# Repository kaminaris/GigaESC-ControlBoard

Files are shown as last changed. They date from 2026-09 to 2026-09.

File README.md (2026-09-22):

# GigaControl

Compact six-layer control card for modular GigaESC motor controllers. The MCU, CAN transceiver, IMU and signal conditioning live here; the MOSFET power stage and power supply are separate boards.

## Board views

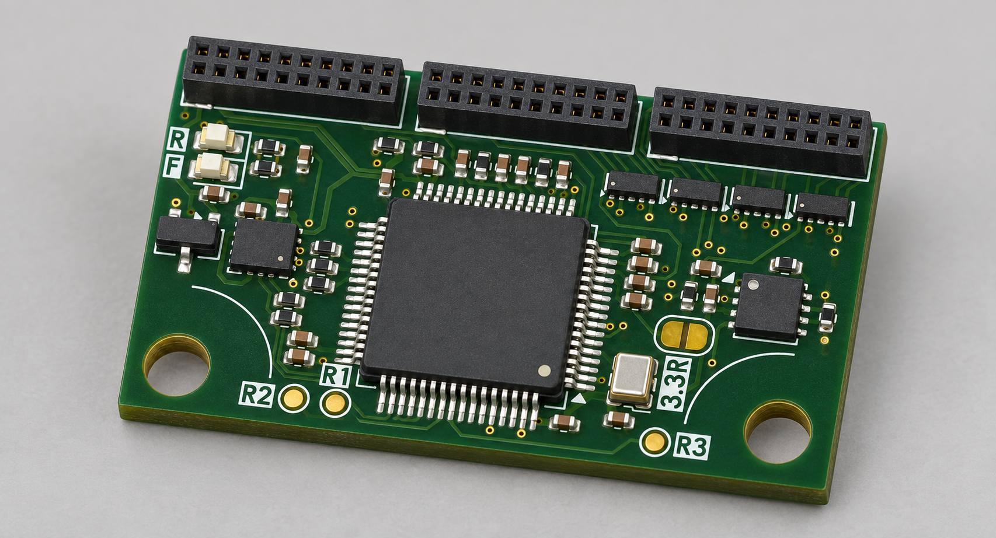
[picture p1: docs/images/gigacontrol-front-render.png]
GigaControl component side


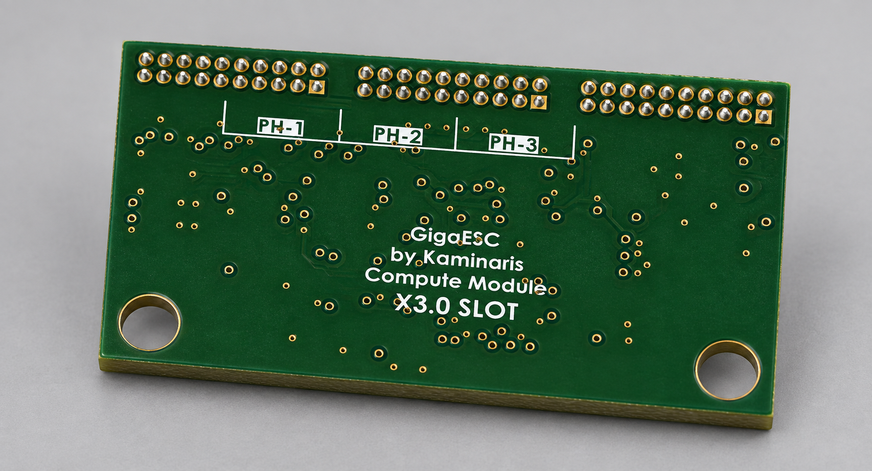
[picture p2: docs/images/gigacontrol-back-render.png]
GigaControl back side


## Hardware

- STM32F405RGT6 with an 8 MHz oscillator.
- SIT3051 CAN transceiver with onboard 120 Ω termination.
- LSM6DS3TR-C IMU on I²C.
- REF3033 analog supply/reference, also exported to the power board.
- Three 1 mm pitch 2×10 female sockets for power, PWM, feedback and external interfaces.
- USB data, SWD, Hall inputs, motor temperature, SERVO, UART and shared SPI/ADC signals pass through the power board.

Open `GigaControl.kicad_pro` in KiCad 10. Local symbols and footprints are included. Keep `HDR-TH_20P-P1.00-V-F-R2-C10-S1.00.step` beside the project for the connector models. Some other models still use `KICAD9_3DMODEL_DIR`; configure that variable if they are missing in KiCad 10.

See [connector pinout](CONNECTOR_PINOUT.md) for the current interface and [firmware adaptation guide](bldc-config/VESC-CONFIG-GUIDE.md) for the supplied VESC configuration template.

## Design notes

- 1 µF VCAP capacitors, the shared SPI/ADC filtering and the REF3033 arrangement are intentional choices reported tested by the designer. This does not imply validation of every optional interface mode.
- Bridge JP1 only when U3 (REF3033) is not fitted; it supplies VDDA from the main 3.3 V rail.
- Phase numbering is local to each board. The current GigaDFN56 pairing exchanges phase groups 1 and 3 consistently across PWM and feedback; phase 2 is unchanged.
- Adapt the firmware configuration to the actual power board and application before use.

## Repository housekeeping

Keep the KiCad project, active schematic sheets (`MCU`, `Filters`, `CAN`, `IMU`), local libraries, library tables, connector STEP model and firmware configuration sources.

Cleanup candidates, not deleted:

- Regenerable/local files: `fp-info-cache`, `GigaControl.dsn`, `GigaControl.step`, `.idea/`, `*.kicad_prl`, and `_autosave-*`.
- Old recovery files: `X3.0CH-Library.bak` and `GigaControl-backups/`, once their contents are no longer needed. Leave active lock files alone while KiCad is open.
- Unreferenced schematic files: `Connectors.kicad_sch`, `ESP32.kicad_sch`, and the empty `Power.kicad_sch`. Archive or remove after confirming they are not wanted as design references.
- Legacy footprints: `X3.0CH-Master`, `X3.0CH`, and `SolderJumper-3-0.5-Small` are not used by the current board; retain if other projects share this library.
- `production/` contains generated outputs; preserve any release/manufacturing records that still matter.

Review on 2026-09-22: saved-board DRC reports no violations, unconnected items or schematic mismatches. ERC has one warning for PB2 tied to GND. These checks do not replace hardware validation.

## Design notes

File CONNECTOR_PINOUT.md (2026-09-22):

# GigaControl connector pinout

Generated from the saved schematic on 2026-09-22. Pin numbers refer to the control-card sockets, not a viewing direction. Match numbered physical contacts on the mating power board.

J1–J3: 1 mm pitch 2×10 female sockets, local footprint `Hanxia_HX_PM1.0-2x10P_ZC`.

| Connector | Odd pin | Signal | Even pin | Signal |
|---|---:|---|---:|---|
| J1 | 1 | `+5V` | 2 | `GND` |
| J1 | 3 | `+3.3V` | 4 | `+3.3REF` |
| J1 | 5 | `POWER-STAGE-DISABLE` | 6 | `POWER-STAGE-LOCKOUT` |
| J1 | 7 | `MOSTEMP3` | 8 | `IN-V` |
| J1 | 9 | `H3` | 10 | `GND` |
| J1 | 11 | `L3` | 12 | `GND` |
| J1 | 13 | `CURR3-FILTERED` | 14 | `GND` |
| J1 | 15 | `VSENSE3` | 16 | `GND` |
| J1 | 17 | `MOSTEMP2` | 18 | `GND` |
| J1 | 19 | `H2` | 20 | `GND` |
| J2 | 1 | `L2` | 2 | `GND` |
| J2 | 3 | `CURR2-FILTERED` | 4 | `GND` |
| J2 | 5 | `VSENSE2` | 6 | `GND` |
| J2 | 7 | `MOSTEMP1` | 8 | `GND` |
| J2 | 9 | `H1` | 10 | `GND` |
| J2 | 11 | `L1` | 12 | `GND` |
| J2 | 13 | `CURR1-FILTERED` | 14 | `GND` |
| J2 | 15 | `VSENSE1` | 16 | `GND` |
| J2 | 17 | `SPI1-NSS` | 18 | `SPI1-MOSI` |
| J2 | 19 | `SPI1-SCK-ADC` | 20 | `SPI1-MISO-ADC2` |
| J3 | 1 | `USBD+` | 2 | `USBD-` |
| J3 | 3 | `SWDIO` | 4 | `GND` |
| J3 | 5 | `SWCLK` | 6 | `I2C2-SDA/USART3-RX` |
| J3 | 7 | `GND` | 8 | `I2C2-SCL/USART3-TX` |
| J3 | 9 | `HALL1-IN` | 10 | `GND` |
| J3 | 11 | `HALL2-IN` | 12 | `SERVO` |
| J3 | 13 | `HALL3-IN` | 14 | `IN-CANL` |
| J3 | 15 | `TEMPMOTOR-IN` | 16 | `IN-CANH` |
| J3 | 17 | `NRST` | 18 | `GND` |
| J3 | 19 | `ESP-TX` | 20 | `ESP-RX` |

J1/J2/J3 mate with GigaDFN56 J31/J32/J33 respectively. Control phase 1 maps to power-board phase 3, phase 2 to phase 2, and phase 3 to phase 1; each mapping includes H, L, current, phase voltage and MOSFET temperature. Other signals match directly.

J1 pin 4 exports the analog reference; J1 pin 8 receives divided bus voltage. No raw battery voltage crosses this interface. USB carries data and ground only; the external connector is on the power board.

The connectors are unkeyed. Verify orientation, insertion depth and mechanical support against the assembled boards.

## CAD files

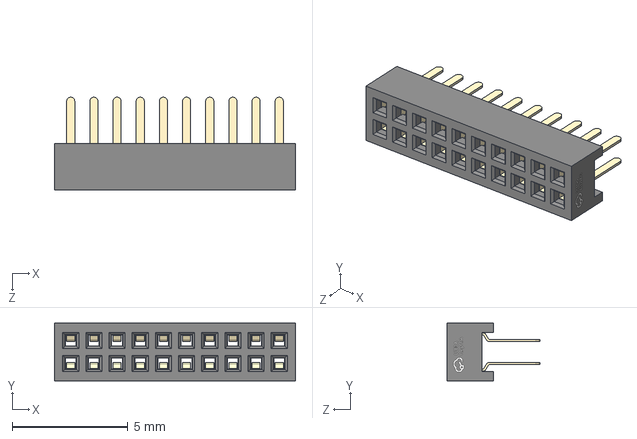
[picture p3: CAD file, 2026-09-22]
HDR-TH_20P-P1.00-V-F-R2-C10-S1.00.step
10.4 x 2.50 x 4.00 mm

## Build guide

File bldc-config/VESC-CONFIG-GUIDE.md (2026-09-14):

# BLDC / VESC config adaptation guide

The files in this folder are a **starting hardware configuration** for this compute module:

- `hw_giga_devkit_xkb_v3.h`
- `hw_giga_devkit_xkb_v3.c`

They are meant to be reused when building a custom VESC power board around this module, but several values must be updated for the final hardware.

## What this config represents

- Compute-module side (STM32, interface signals, logic-level control, basic mappings)
- A reference power-stage assumption used during development

If your gate driver, shunts, divider ratios, thermistors, or protection strategy differ, this config must be edited before production use.

## Integration into VESC firmware

1. Copy these two files into your VESC firmware hardware config area.
2. Build with the matching target:
   - `make -j24 giga_devkit_xkb_v3`
3. Flash firmware and validate on low-voltage/current-limited supply first.

## Parameters that usually require changes

| Area | Where | Typical reason to change |
|---|---|---|
| Input voltage scaling | `VIN_R1`, `VIN_R2` in `.h` | Your bus-voltage divider uses different resistor values |
| Current measurement model | `CURRENT_SHUNT_RES`, `CURRENT_AMP_GAIN`, `BOOST_*` in `.h` | Different shunt value, amplifier gain, or sensor topology |
| Current calibration | `CURRENT_CAL1/2/3` in `.h` | Remove phase gain mismatch after hardware bring-up |
| ADC channel mapping | `hw_setup_adc_channels()` in `.c`, ADC index macros in `.h` | Your analog nets are routed to different MCU ADC pins |
| Temperature model | `NTC_TEMP_*`, beta assumptions in `.h` | Different NTC beta/value or placement |
| Driver polarity / fault behavior | `ENABLE_GATE`, `DISABLE_GATE`, `IS_DRV_FAULT` in `.h` | Different gate driver enable polarity or fault pin polarity |
| Dead time | `HW_DEAD_TIME_NSEC` in `.h` | Different MOSFET + driver switching characteristics |
| Electrical limits | `HW_LIM_*`, `MCCONF_L_*`, `MCCONF_FOC_*` in `.h` | Match voltage, current, thermal, ERPM, and duty limits to your power stage |

## Minimum checklist before first full-power test

1. Confirm pinout/mappings against your power-board schematic.
2. Recalculate and set voltage divider and current-sense parameters.
3. Verify gate enable and fault polarity with scope/logic checks.
4. Set conservative voltage/current/temperature limits.
5. Calibrate current channels (`CURRENT_CAL1/2/3`), then re-test.
6. Increase limits gradually only after thermal and fault behavior is verified.

## Recommended workflow for new power boards

1. Keep this compute-module mapping as baseline.
2. Fork the config under a new board name (do not overwrite blindly).
3. Update electrical model values first (voltage/current/temp).
4. Update protection and limits.
5. Perform staged bring-up: low-voltage -> nominal voltage -> load testing.

This approach keeps the compute module reusable while allowing safe tuning for each new power board design.

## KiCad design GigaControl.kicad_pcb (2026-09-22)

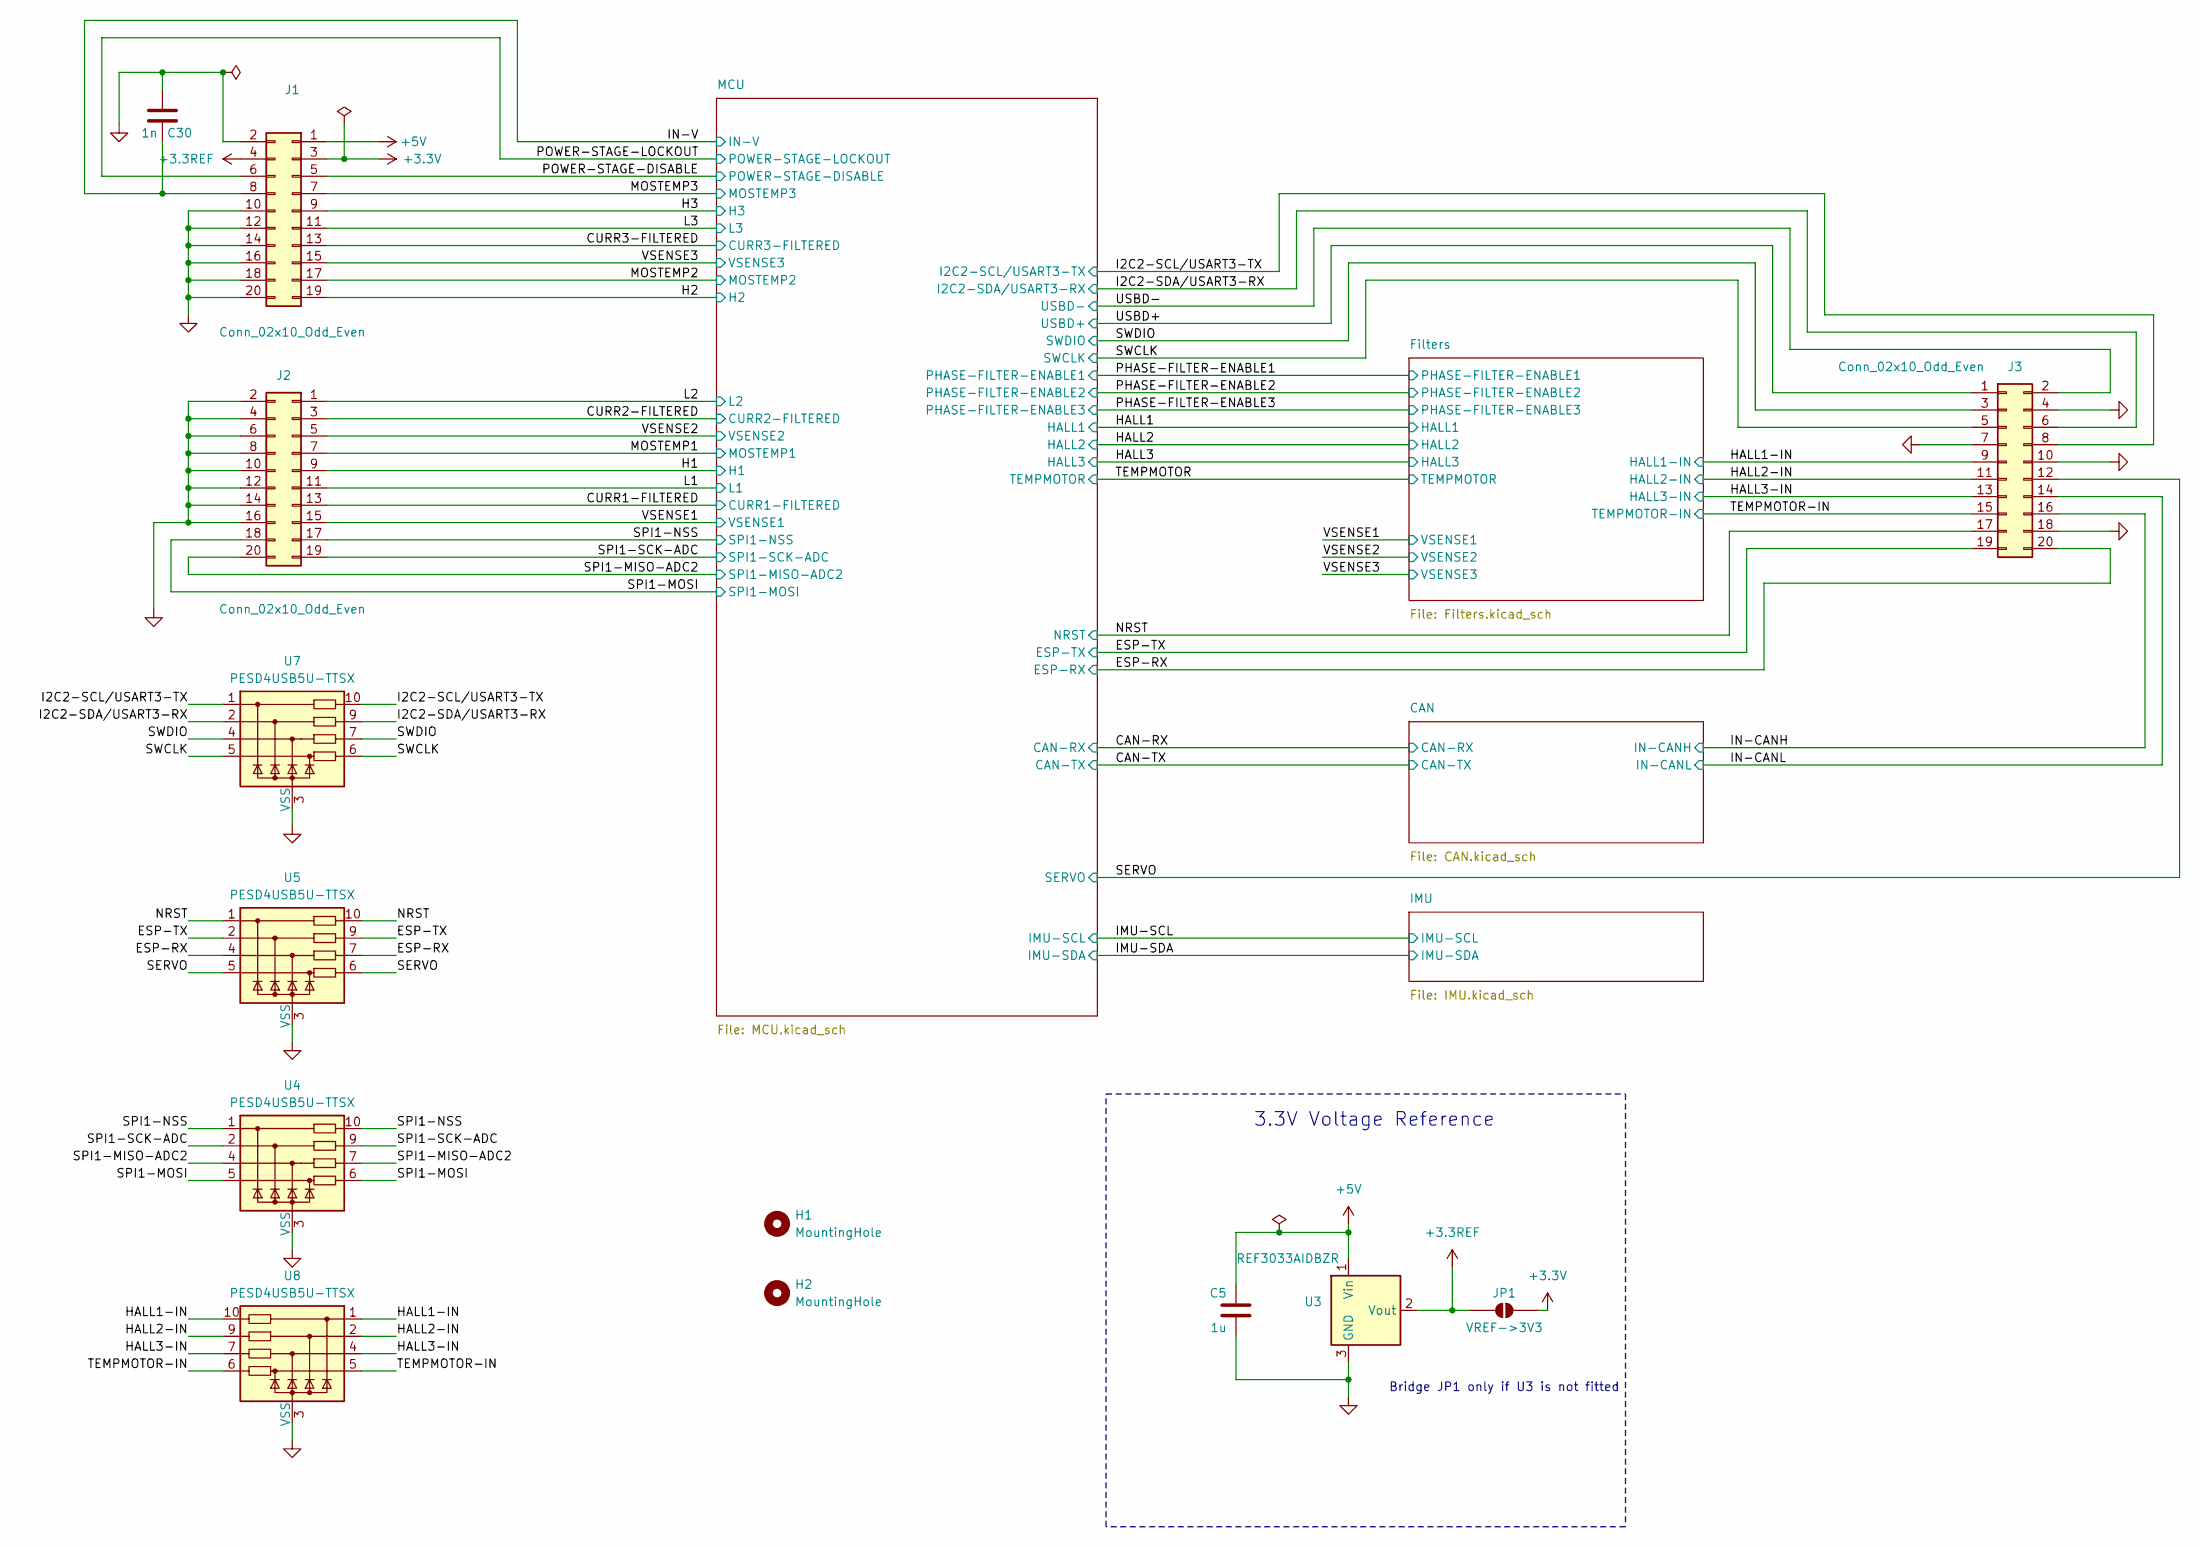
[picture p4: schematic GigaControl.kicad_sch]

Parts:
C5: 1u; C_0402_1005Metric; MPN C52923
C30: 1n; C_0402_1005Metric; MPN C1523
H1, H2: MountingHole; MountingHole_3.2mm_M3_DIN965
J1, J2, J3: Conn_02x10_Odd_Even; Hanxia_HX_PM1.0-2x10P_ZC; MPN HX PM1.0-2x10P ZC; LCSC C22465702
JP1: VREF->3V3; SolderJumper-2_P1.3mm_Open_RoundedPad1.0x1.5mm
U3: REF3033AIDBZR; SOT-23; MPN C36658; JLCRotOffset 0
U4, U5, U7, U8: PESD4USB5U-TTSX; Diodes_UDFN-10_1x2.5mm_P0.5mm

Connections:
+3.3REF: J1.4, JP1.1 (A), U3.2 (Vout); also elsewhere on the board
+3.3V: J1.3, JP1.2 (B); also elsewhere on the board
+5V: C5.1, J1.1, U3.1 (Vin)
/CURR1-FILTERED: J2.13; also elsewhere on the board
/CURR2-FILTERED: J2.3; also elsewhere on the board
/CURR3-FILTERED: J1.13; also elsewhere on the board
/ESP-RX: J3.20, U5.4, U5.7; also elsewhere on the board
/ESP-TX: J3.19, U5.2, U5.9; also elsewhere on the board
/H1: J2.9; also elsewhere on the board
/H2: J1.19; also elsewhere on the board
/H3: J1.9; also elsewhere on the board
/HALL1-IN: J3.9, U8.1, U8.10; also elsewhere on the board
/HALL2-IN: J3.11, U8.2, U8.9; also elsewhere on the board
/HALL3-IN: J3.13, U8.4, U8.7; also elsewhere on the board
/I2C2-SCL/USART3-TX: J3.8, U7.1, U7.10; also elsewhere on the board
/I2C2-SDA/USART3-RX: J3.6, U7.2, U7.9; also elsewhere on the board
/IN-CANH: J3.16; also elsewhere on the board
/IN-CANL: J3.14; also elsewhere on the board
/IN-V: C30.1, J1.8; also elsewhere on the board
/L1: J2.11; also elsewhere on the board
/L2: J2.1; also elsewhere on the board
/L3: J1.11; also elsewhere on the board
/MOSTEMP1: J2.7; also elsewhere on the board
/MOSTEMP2: J1.17; also elsewhere on the board
/MOSTEMP3: J1.7; also elsewhere on the board
/NRST: J3.17, U5.1, U5.10; also elsewhere on the board
/POWER-STAGE-DISABLE: J1.5; also elsewhere on the board
/POWER-STAGE-LOCKOUT: J1.6; also elsewhere on the board
/SERVO: J3.12, U5.5, U5.6; also elsewhere on the board
/SPI1-MISO-ADC2: J2.20, U4.4, U4.7; also elsewhere on the board
/SPI1-MOSI: J2.18, U4.5, U4.6; also elsewhere on the board
/SPI1-NSS: J2.17, U4.1, U4.10; also elsewhere on the board
/SPI1-SCK-ADC: J2.19, U4.2, U4.9; also elsewhere on the board
/SWCLK: J3.5, U7.5, U7.6; also elsewhere on the board
/SWDIO: J3.3, U7.4, U7.7; also elsewhere on the board
/TEMPMOTOR-IN: J3.15, U8.5, U8.6; also elsewhere on the board
/USBD+: J3.1; also elsewhere on the board
/USBD-: J3.2; also elsewhere on the board
/VSENSE1: J2.15; also elsewhere on the board
/VSENSE2: J2.5; also elsewhere on the board
/VSENSE3: J1.15; also elsewhere on the board
GND: C5.2, C30.2, J1.2, J1.10, J1.12, J1.14, J1.16, J1.18, J1.20, J2.2, J2.4, J2.6, J2.8, J2.10, J2.12, J2.14, J2.16, J3.4, J3.7, J3.10, J3.18, U3.3 (GND), U4.3 (VSS), U4.8 (VSS), U5.3 (VSS), U5.8 (VSS), U7.3 (VSS), U7.8 (VSS), U8.3 (VSS), U8.8 (VSS); also elsewhere on the board

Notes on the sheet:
3.3V Voltage Reference
Bridge JP1 only if U3 is not fitted

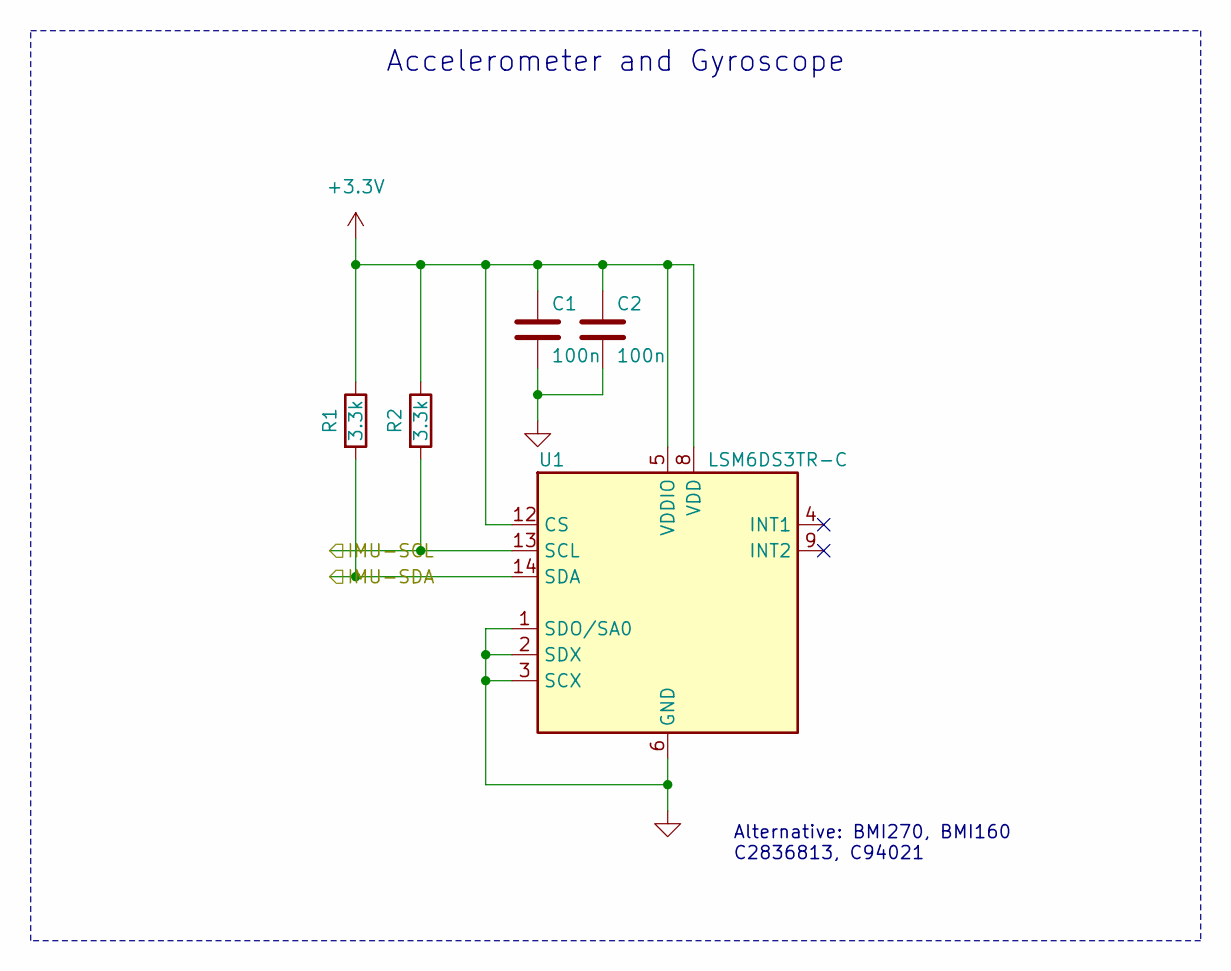
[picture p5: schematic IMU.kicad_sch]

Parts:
C1, C2: 100n; C_0402_1005Metric; MPN C1525
R1, R2: 3.3k; R_0402_1005Metric; MPN C25890
U1: LSM6DS3TR-C; LGA-14_3x2.5mm_P0.5mm; MPN C967633; JLCRotOffset -90

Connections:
+3.3V: C1.1, C2.1, R1.1, R2.1, U1.5 (VDDIO), U1.8 (VDD), U1.12 (CS); also elsewhere on the board
/IMU-SCL: R2.2, U1.13 (SCL); also elsewhere on the board
/IMU-SDA: R1.2, U1.14 (SDA); also elsewhere on the board
GND: C1.2, C2.2, U1.1 (SDO/SA0), U1.2 (SDX), U1.3 (SCX), U1.6 (GND), U1.7 (GND); also elsewhere on the board

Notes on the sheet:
Alternative: BMI270, BMI160 C2836813, C94021
Accelerometer and Gyroscope

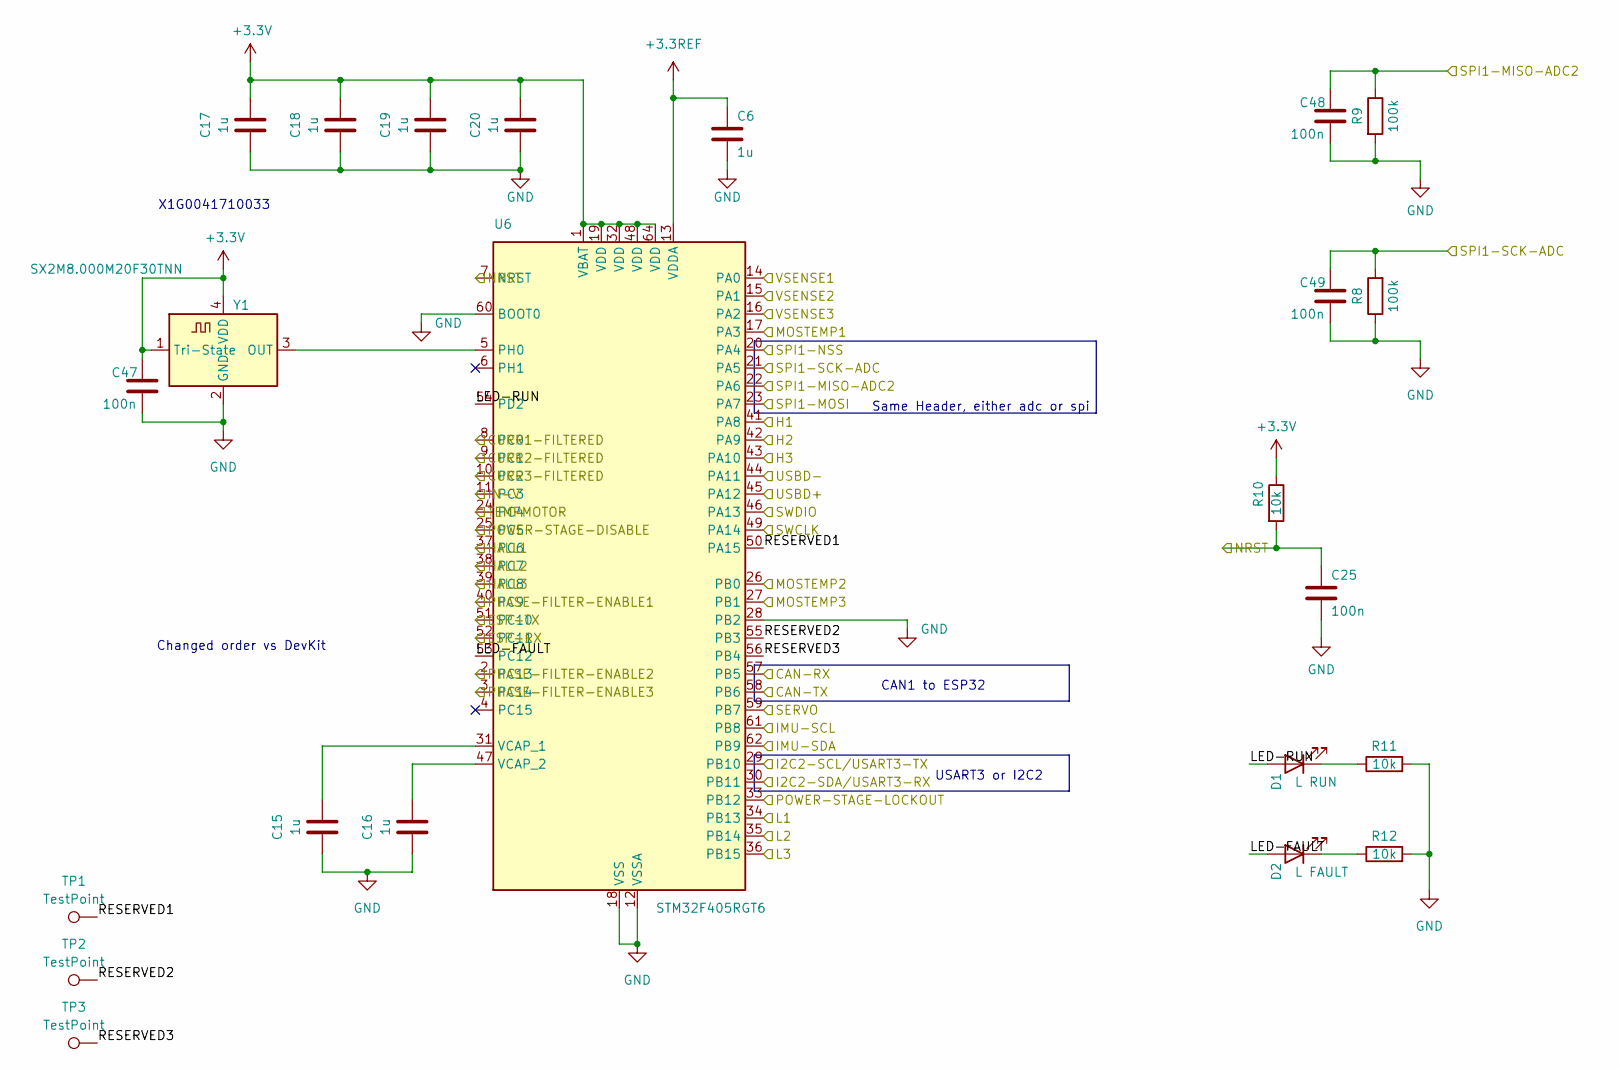
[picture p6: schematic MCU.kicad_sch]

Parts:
C6, C15, C16, C17, C18, C19, C20: 1u; C_0402_1005Metric; MPN C52923
C25, C47, C48, C49: 100n; C_0402_1005Metric; MPN C1525
D1: L RUN; LED_0603_1608Metric; MPN C2290
D2: L FAULT; LED_0603_1608Metric; MPN C2286
R8, R9: 100k; R_0402_1005Metric; MPN C25741
R10, R11, R12: 10k; R_0402_1005Metric; MPN C25744
TP1, TP2, TP3: TestPoint; TestPoint_Pad_D1.0mm
U6: STM32F405RGT6; LQFP-64_10x10mm_P0.5mm; MPN C15742
Y1: SX2M8.000M20F30TNN; Oscillator_SMD_ECS_2520MV-xxx-xx-4Pin_2.5x2.0mm; MPN C2901594

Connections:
+3.3REF: C6.1, U6.13 (VDDA); also elsewhere on the board
+3.3V: C17.1, C18.1, C19.1, C20.1, C47.1, R10.1, U6.1 (VBAT), U6.19 (VDD), U6.32 (VDD), U6.48 (VDD), U6.64 (VDD), Y1.1 (Tri-State), Y1.4 (VDD); also elsewhere on the board
/CAN-RX: U6.57 (PB5); also elsewhere on the board
/CAN-TX: U6.58 (PB6); also elsewhere on the board
/CURR1-FILTERED: U6.8 (PC0); also elsewhere on the board
/CURR2-FILTERED: U6.9 (PC1); also elsewhere on the board
/CURR3-FILTERED: U6.10 (PC2); also elsewhere on the board
/ESP-RX: U6.52 (PC11); also elsewhere on the board
/ESP-TX: U6.51 (PC10); also elsewhere on the board
/H1: U6.41 (PA8); also elsewhere on the board
/H2: U6.42 (PA9); also elsewhere on the board
/H3: U6.43 (PA10); also elsewhere on the board
/HALL1: U6.37 (PC6); also elsewhere on the board
/HALL2: U6.38 (PC7); also elsewhere on the board
/HALL3: U6.39 (PC8); also elsewhere on the board
/I2C2-SCL/USART3-TX: U6.29 (PB10); also elsewhere on the board
/I2C2-SDA/USART3-RX: U6.30 (PB11); also elsewhere on the board
/IMU-SCL: U6.61 (PB8); also elsewhere on the board
/IMU-SDA: U6.62 (PB9); also elsewhere on the board
/IN-V: U6.11 (PC3); also elsewhere on the board
/L1: U6.34 (PB13); also elsewhere on the board
/L2: U6.35 (PB14); also elsewhere on the board
/L3: U6.36 (PB15); also elsewhere on the board
/MCU/LED-FAULT: D2.2 (A), U6.53 (PC12)
/MCU/LED-RUN: D1.2 (A), U6.54 (PD2)
/MCU/RESERVED1: TP1.1 (1_1), U6.50 (PA15)
/MCU/RESERVED2: TP2.1 (1_1), U6.55 (PB3)
/MCU/RESERVED3: TP3.1 (1_1), U6.56 (PB4)
/MOSTEMP1: U6.17 (PA3); also elsewhere on the board
/MOSTEMP2: U6.26 (PB0); also elsewhere on the board
/MOSTEMP3: U6.27 (PB1); also elsewhere on the board
/NRST: C25.1, R10.2, U6.7 (NRST); also elsewhere on the board
/PHASE-FILTER-ENABLE1: U6.40 (PC9); also elsewhere on the board
/PHASE-FILTER-ENABLE2: U6.2 (PC13); also elsewhere on the board
/PHASE-FILTER-ENABLE3: U6.3 (PC14); also elsewhere on the board
/POWER-STAGE-DISABLE: U6.25 (PC5); also elsewhere on the board
/POWER-STAGE-LOCKOUT: U6.33 (PB12); also elsewhere on the board
/SERVO: U6.59 (PB7); also elsewhere on the board
/SPI1-MISO-ADC2: C48.1, R9.1, U6.22 (PA6); also elsewhere on the board
/SPI1-MOSI: U6.23 (PA7); also elsewhere on the board
/SPI1-NSS: U6.20 (PA4); also elsewhere on the board
/SPI1-SCK-ADC: C49.1, R8.2, U6.21 (PA5); also elsewhere on the board
/SWCLK: U6.49 (PA14); also elsewhere on the board
/SWDIO: U6.46 (PA13); also elsewhere on the board
/TEMPMOTOR: U6.24 (PC4); also elsewhere on the board
/USBD+: U6.45 (PA12); also elsewhere on the board
/USBD-: U6.44 (PA11); also elsewhere on the board
/VSENSE1: U6.14 (PA0); also elsewhere on the board
/VSENSE2: U6.15 (PA1); also elsewhere on the board
/VSENSE3: U6.16 (PA2); also elsewhere on the board
GND: C6.2, C15.2, C16.2, C17.2, C18.2, C19.2, C20.2, C25.2, C47.2, C48.2, C49.2, R8.1, R9.2, R11.2, R12.2, U6.12 (VSSA), U6.18 (VSS), U6.28 (PB2), U6.60 (BOOT0), U6.63 (VSS), Y1.2 (GND); also elsewhere on the board
unnamed: D1.1 (K), R11.1
unnamed: D2.1 (K), R12.1
unnamed: U6.5 (PH0), Y1.3 (OUT)
unnamed: C15.1, U6.31 (VCAP_1)
unnamed: C16.1, U6.47 (VCAP_2)

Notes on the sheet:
CAN1 to ESP32
USART3 or I2C2
Changed order vs DevKit
X1G0041710033
Same Header, either adc or spi

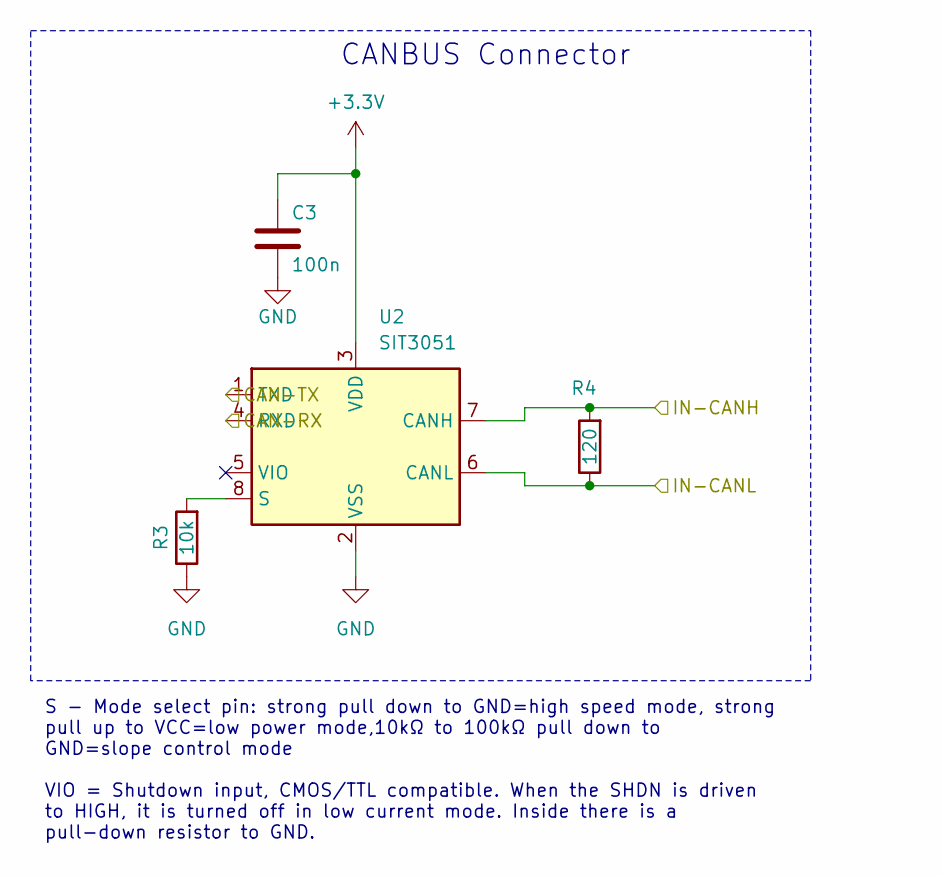
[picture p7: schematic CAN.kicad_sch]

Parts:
C3: 100n; C_0402_1005Metric; MPN C1525
R3: 10k; R_0402_1005Metric; MPN C25744
R4: 120; R_0402_1005Metric; MPN C25079
U2: SIT3051; DFN-8-1EP_3x3mm_P0.65mm_EP1.55x2.4mm; MPN C601078

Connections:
+3.3V: C3.1, U2.3 (VDD); also elsewhere on the board
/CAN-RX: U2.4 (RXD); also elsewhere on the board
/CAN-TX: U2.1 (TXD); also elsewhere on the board
/IN-CANH: R4.2, U2.7 (CANH); also elsewhere on the board
/IN-CANL: R4.1, U2.6 (CANL); also elsewhere on the board
GND: C3.2, R3.1, U2.2 (VSS), U2.9 (VSS); also elsewhere on the board
unnamed: R3.2, U2.8 (S)

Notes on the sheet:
CANBUS Connector
S - Mode select pin: strong pull down to GND=high speed mode, strong pull up to VCC=low power mode,10kΩ to 100kΩ pull down to GND=slope control mode VIO = Shutdown input, CMOS/TTL compatible. When the SHDN is driven to HIGH, it is turned off in low current mode. Inside there is a pull-down resistor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

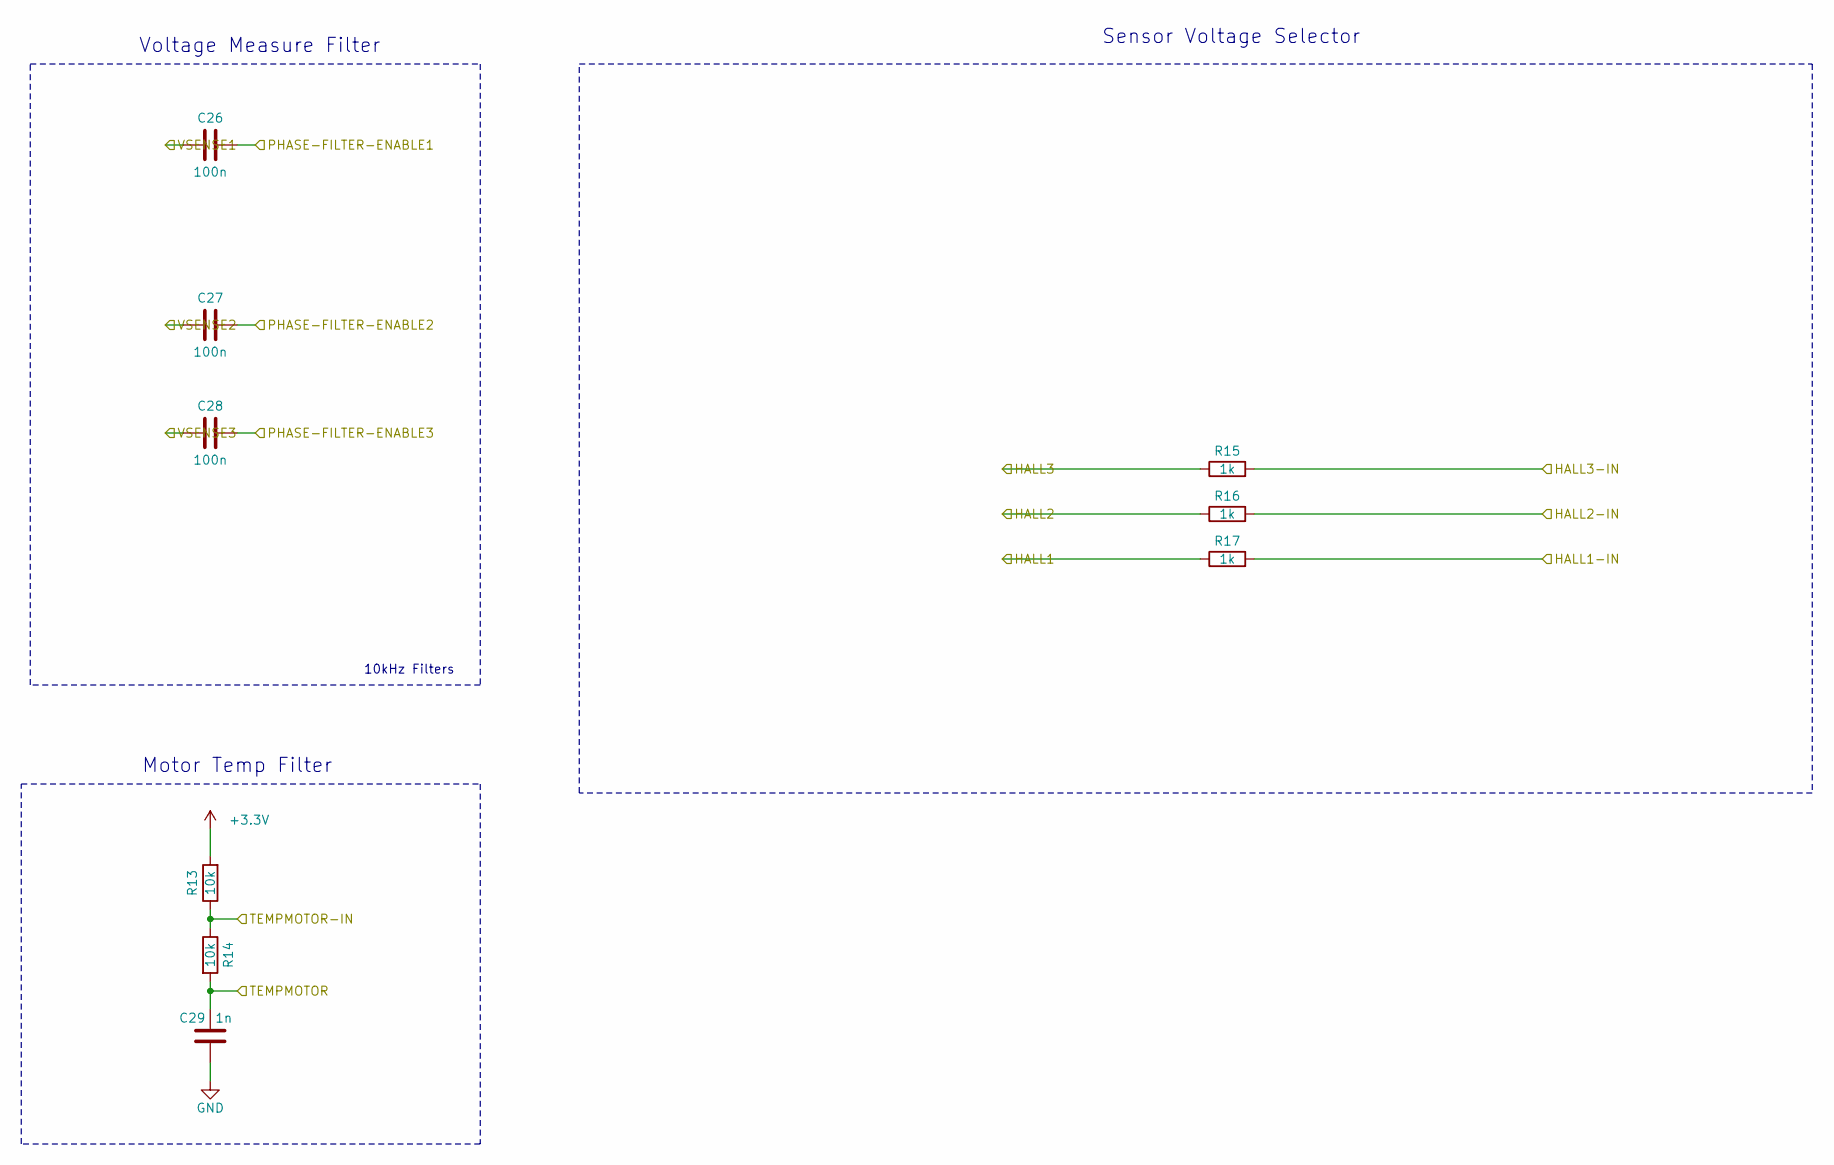
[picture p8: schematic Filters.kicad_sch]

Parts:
C26, C27, C28: 100n; C_0402_1005Metric; MPN C1525
C29: 1n; C_0402_1005Metric; MPN C1523
R13, R14: 10k; R_0402_1005Metric; MPN C25744
R15, R16, R17: 1k; R_0402_1005Metric; MPN C11702

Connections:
+3.3V: R13.2; also elsewhere on the board
/HALL1: R17.1; also elsewhere on the board
/HALL1-IN: R17.2; also elsewhere on the board
/HALL2: R16.1; also elsewhere on the board
/HALL2-IN: R16.2; also elsewhere on the board
/HALL3: R15.1; also elsewhere on the board
/HALL3-IN: R15.2; also elsewhere on the board
/PHASE-FILTER-ENABLE1: C26.2; also elsewhere on the board
/PHASE-FILTER-ENABLE2: C27.2; also elsewhere on the board
/PHASE-FILTER-ENABLE3: C28.2; also elsewhere on the board
/TEMPMOTOR: C29.1, R14.2; also elsewhere on the board
/TEMPMOTOR-IN: R13.1, R14.1; also elsewhere on the board
/VSENSE1: C26.1; also elsewhere on the board
/VSENSE2: C27.1; also elsewhere on the board
/VSENSE3: C28.1; also elsewhere on the board
GND: C29.2; also elsewhere on the board

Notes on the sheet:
10kHz Filters
Sensor Voltage Selector
Motor Temp Filter
Voltage Measure Filter

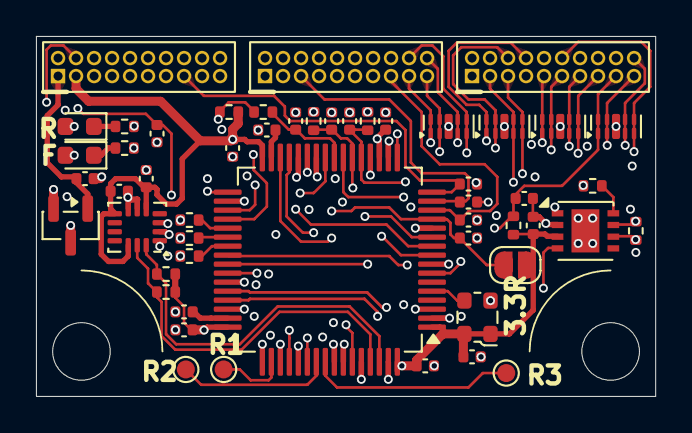
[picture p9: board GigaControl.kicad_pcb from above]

Board: 6 copper layers, 34.4 x 20.0 mm, 54 parts (0 on the bottom side), 64 nets.

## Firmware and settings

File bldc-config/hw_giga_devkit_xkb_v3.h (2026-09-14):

/*
	Copyright 2018 Benjamin Vedder	benjamin@vedder.se

	This file is part of the VESC firmware.

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
	You should have received a copy of the GNU General Public License
	along with this program.  If not, see <http://www.gnu.org/licenses/>.
*/

///////////////
/// To compile, go ubuntu wsl2 and run: make -j24 giga_devkit_xkb_v3
///////////////

#ifndef HW_GIGA_DEVKIT_CORE_V2_H_
#define HW_GIGA_DEVKIT_CORE_V2_H_

#define HW_NAME							"GigaESC DevKitX3.0-CH"

// HW properties
#define HW_HAS_3_SHUNTS
#define INVERTED_SHUNT_POLARITY
#define HW_HAS_PHASE_FILTERS
// #define HW_USE_25MHZ_EXT_CLOCK
// #define HW_USE_BRK

// Macros

#define HW_ADC_CHANNELS			18
#define HW_ADC_INJ_CHANNELS		3
#define HW_ADC_NBR_CONV			6

// ADC Indexes - refer to .c for descriptions
#define ADC_IND_CURR1			0
#define ADC_IND_CURR2			1
#define ADC_IND_CURR3			2

#define ADC_IND_VIN_SENS		8
#define ADC_IND_SENS1			3
#define ADC_IND_SENS2			4
#define ADC_IND_SENS3			5

#define ADC_IND_EXT				6
#define ADC_IND_EXT2			7

#define ADC_IND_EXT3			10

#define ADC_IND_TEMP_MOS		11
#define ADC_IND_TEMP_MOS_2		12
#define ADC_IND_TEMP_MOS_3		13
#define ADC_IND_TEMP_MOTOR		15

#define ADC_IND_VREFINT			9

// ADC macros and settings

// Component parameters (can be overridden)
#ifndef V_REG
#define V_REG					3.30
#endif
#ifndef VIN_R1
#define VIN_R1					(348.0f * 3.0f)
#endif
#ifndef VIN_R2
#define VIN_R2					(18.7f)
#endif

// Hall sensor sees only a fraction of entire current ex shunt will see 5A while hall sees 1.471A
// We only measure 1.471A out of 6.471A total current so we need to extrapolate it
// Original formula is ((V_REG / 4095.0) / (CURRENT_SHUNT_RES * CURRENT_AMP_GAIN))
#define BOOST_SHUNT             0.0002f
#define BOOST_HALL_INTERNAL_RES 0.00068f
#define BOOST_HALL_SENS         0.033f
#define CURRENT_RATIO           ((BOOST_SHUNT + BOOST_HALL_INTERNAL_RES) / BOOST_SHUNT)

// Effective resistance seen by the measurement
#define CURRENT_SHUNT_RES       BOOST_HALL_SENS
#define CURRENT_AMP_GAIN        (1.0f/CURRENT_RATIO)

/*
#ifndef CURRENT_AMP_GAIN
#define CURRENT_AMP_GAIN		20.0
#endif
// shunt gives 4x the voltage, so divide by 4
#ifndef CURRENT_SHUNT_RES
#define CURRENT_SHUNT_RES		(0.0002)*4
#endif
*/

#define CURRENT_CAL1 0.716605
#define CURRENT_CAL2 0.716605
#define CURRENT_CAL3 0.716605

// Input voltage
#define GET_INPUT_VOLTAGE()		((V_REG / 4095.0) * (float)ADC_Value[ADC_IND_VIN_SENS] * ((VIN_R1 + VIN_R2) / VIN_R2))

// NTC Termistors
#define NTC_RES(adc_val)		((4095.0 * 10000.0) / adc_val - 10000.0)

#define NTC_RES_MOTOR(adc_val)	(10000.0 / ((4095.0 / (float)adc_val) - 1.0)) // Motor temp sensor on low side
#define NTC_TEMP_MOTOR(beta)	(1.0 / ((logf(NTC_RES_MOTOR(ADC_Value[ADC_IND_TEMP_MOTOR]) / 10000.0) / beta) + (1.0 / 298.15)) - 273.15)

#define NTC_TEMP(adc_ind)		hw_giga_get_temp()
#define NTC_TEMP_MOS1()			(1.0 / ((logf(NTC_RES(ADC_Value[ADC_IND_TEMP_MOS]) / 10000.0) / 3380.0) + (1.0 / 298.15)) - 273.15)
#define NTC_TEMP_MOS2()			(1.0 / ((logf(NTC_RES(ADC_Value[ADC_IND_TEMP_MOS_2]) / 10000.0) / 3380.0) + (1.0 / 298.15)) - 273.15)
#define NTC_TEMP_MOS3()			(1.0 / ((logf(NTC_RES(ADC_Value[ADC_IND_TEMP_MOS_3]) / 10000.0) / 3380.0) + (1.0 / 298.15)) - 273.15)

// Voltage on ADC channel
#define ADC_VOLTS(ch)			((float)ADC_Value[ch] / 4096.0 * V_REG)

// Double samples in beginning and end for positive current measurement.
// Useful when the shunt sense traces have noise that causes offset.
#ifndef CURR1_DOUBLE_SAMPLE
#define CURR1_DOUBLE_SAMPLE		0
#endif
#ifndef CURR2_DOUBLE_SAMPLE
#define CURR2_DOUBLE_SAMPLE		0
#endif
#ifndef CURR3_DOUBLE_SAMPLE
#define CURR3_DOUBLE_SAMPLE		0
#endif

#define LED_GREEN_GPIO			GPIOD
#define LED_GREEN_PIN			2
#define LED_RED_GPIO			GPIOC
#define LED_RED_PIN				12

#define LED_GREEN_ON()			palSetPad(LED_GREEN_GPIO, LED_GREEN_PIN)
#define LED_GREEN_OFF()			palClearPad(LED_GREEN_GPIO, LED_GREEN_PIN)
#define LED_RED_ON()			palSetPad(LED_RED_GPIO, LED_RED_PIN)
#define LED_RED_OFF()			palClearPad(LED_RED_GPIO, LED_RED_PIN)

// Aux - TCKE812NA,RF -- not present
#define AUX_GPIO			GPIOB
#define AUX_PIN				3
#define AUX_ON()			palSetPad(AUX_GPIO, AUX_PIN)
#define AUX_OFF()			palClearPad(AUX_GPIO, AUX_PIN)

// Sensor port voltage control -- not present
#define SENSOR_VOLTAGE_GPIO		GPIOB
#define SENSOR_VOLTAGE_PIN		4
#define SENSOR_PORT_5V()		palSetPad(SENSOR_VOLTAGE_GPIO, SENSOR_VOLTAGE_PIN);
#define SENSOR_PORT_3V3()		palClearPad(SENSOR_VOLTAGE_GPIO, SENSOR_VOLTAGE_PIN);

// Phase voltage filter
#define PHASE_FILTER_GPIO		GPIOC
#define PHASE_FILTER_PIN1		9
#define PHASE_FILTER_PIN2		13
#define PHASE_FILTER_PIN3		14
#define PHASE_FILTER_OFF()		palSetPad(PHASE_FILTER_GPIO, PHASE_FILTER_PIN1); palSetPad(PHASE_FILTER_GPIO, PHASE_FILTER_PIN2); palSetPad(PHASE_FILTER_GPIO, PHASE_FILTER_PIN3)
#define PHASE_FILTER_ON()		palClearPad(PHASE_FILTER_GPIO, PHASE_FILTER_PIN1); palClearPad(PHASE_FILTER_GPIO, PHASE_FILTER_PIN2); palClearPad(PHASE_FILTER_GPIO, PHASE_FILTER_PIN3)

// Hall filter -- not present
#define HALL_FILTER_GPIO		GPIOC
#define HALL_FILTER_PIN			15
#define HALL_FILTER_OFF()		palSetPad(HALL_FILTER_GPIO, HALL_FILTER_PIN);
#define HALL_FILTER_ON()		palClearPad(HALL_FILTER_GPIO, HALL_FILTER_PIN);

// Current filter is permanently on, set it to unused GPIOs
/*
#define CURRENT_FILTER_GPIO1	GPIOE
#define CURRENT_FILTER_PIN1		3
#define CURRENT_FILTER_GPIO2	GPIOE
#define CURRENT_FILTER_PIN2		4
#define CURRENT_FILTER_GPIO3	GPIOE
#define CURRENT_FILTER_PIN3		5

#define CURRENT_FILTER_ON()		palSetPad(CURRENT_FILTER_GPIO1, CURRENT_FILTER_PIN1); \
 								palSetPad(CURRENT_FILTER_GPIO2, CURRENT_FILTER_PIN2); \
 		                        palSetPad(CURRENT_FILTER_GPIO3, CURRENT_FILTER_PIN3);

#define CURRENT_FILTER_OFF()	palClearPad(CURRENT_FILTER_GPIO1, CURRENT_FILTER_PIN1); \
 								palClearPad(CURRENT_FILTER_GPIO2, CURRENT_FILTER_PIN2); \
 								palClearPad(CURRENT_FILTER_GPIO3, CURRENT_FILTER_PIN3);
*/

// COMM-port ADC GPIOs
#define HW_ADC_EXT_GPIO			GPIOA
#define HW_ADC_EXT_PIN			5
#define HW_ADC_EXT2_GPIO		GPIOA
#define HW_ADC_EXT2_PIN			6


// UART Peripheral
#define HW_UART_DEV             SD3
#define HW_UART_GPIO_AF         GPIO_AF_USART3
#define HW_UART_TX_PORT         GPIOB
#define HW_UART_TX_PIN          10
#define HW_UART_RX_PORT         GPIOB
#define HW_UART_RX_PIN          11

// SPI pins
#define HW_SPI_DEV				SPID1
#define HW_SPI_GPIO_AF			GPIO_AF_SPI1
#define HW_SPI_PORT_NSS			GPIOA
#define HW_SPI_PIN_NSS			4
#define HW_SPI_PORT_SCK			GPIOA
#define HW_SPI_PIN_SCK			5
#define HW_SPI_PORT_MOSI		GPIOA
#define HW_SPI_PIN_MOSI			7
#define HW_SPI_PORT_MISO		GPIOA
#define HW_SPI_PIN_MISO			6
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

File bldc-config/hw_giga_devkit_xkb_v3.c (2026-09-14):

/*
	Copyright 2018 Benjamin Vedder	benjamin@vedder.se

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
	You should have received a copy of the GNU General Public License
	along with this program.  If not, see <http://www.gnu.org/licenses/>.
	*/

#include "hw.h"
#include "ch.h"
#include "hal.h"
#include "stm32f4xx_conf.h"
#include "utils.h"
#include <math.h>
#include "mc_interface.h"
#include "commands.h"
#include "terminal.h"
#include "mcpwm.h"
#include "mcpwm_foc.h"
#include "app.h"
#include "mempools.h"
#include "timeout.h"
#include "stdio.h"
#include "imu.h"

// Variables
static volatile bool i2c_running = false;

// Private functions
static void terminal_cmd_doublepulse(int argc, const char** argv);

// I2C configuration
static const I2CConfig i2cfg = {
	OPMODE_I2C,
	100000,
	STD_DUTY_CYCLE
};

void hw_init_gpio(void) {
	// GPIO clock enable
	RCC_AHB1PeriphClockCmd(RCC_AHB1Periph_GPIOA, ENABLE);
	RCC_AHB1PeriphClockCmd(RCC_AHB1Periph_GPIOB, ENABLE);
	RCC_AHB1PeriphClockCmd(RCC_AHB1Periph_GPIOC, ENABLE);
	RCC_AHB1PeriphClockCmd(RCC_AHB1Periph_GPIOD, ENABLE);

	// LEDs	
	palSetPadMode(LED_GREEN_GPIO, LED_GREEN_PIN, PAL_MODE_OUTPUT_PUSHPULL | PAL_STM32_OSPEED_HIGHEST);
	palSetPadMode(LED_RED_GPIO, LED_RED_PIN, PAL_MODE_OUTPUT_PUSHPULL | PAL_STM32_OSPEED_HIGHEST);

	// HW protection pins
	/*
	palSetPadMode(
		HW_PROTECTION_CLEAR_GPIO,
		HW_PROTECTION_CLEAR_PIN,
		PAL_MODE_OUTPUT_PUSHPULL | PAL_STM32_OSPEED_HIGHEST
	);
	palClearPad(HW_PROTECTION_CLEAR_GPIO, HW_PROTECTION_CLEAR_PIN);
	*/
	// Disable	  
	palSetPadMode(
		HW_POWER_STAGE_DISABLE_GPIO,
		HW_POWER_STAGE_DISABLE_PIN,
		PAL_MODE_OUTPUT_PUSHPULL | PAL_STM32_OSPEED_HIGHEST
	);
	DISABLE_GATE();

	#ifdef HW_USE_BRK
	// BRK Fault pin
	palSetPadMode(BRK_GPIO, BRK_PIN, PAL_MODE_ALTERNATE(GPIO_AF_TIM1));
	#else
	// Soft Lockout
	palSetPadMode(BRK_GPIO, BRK_PIN, PAL_MODE_INPUT);
	#endif

	// AUX
	AUX_OFF();
	palSetPadMode(AUX_GPIO, AUX_PIN, PAL_MODE_OUTPUT_PUSHPULL | PAL_STM32_OSPEED_HIGHEST);

	// Output protection
	//TODO: can this be disabled?
	// palSetPadMode(HW_5V_FAULT_GPIO, HW_5V_FAULT_PIN, PAL_MODE_INPUT_PULLUP);
	// palSetPadMode(HW_3V3_FAULT_GPIO, HW_3V3_FAULT_PIN, PAL_MODE_INPUT_PULLUP);

	// GPIOA Configuration: Channel 1 to 3 as alternate function push-pull
	// H1-H3
	palSetPadMode(GPIOA, 8, PAL_MODE_ALTERNATE(GPIO_AF_TIM1) | PAL_STM32_OSPEED_HIGHEST | PAL_STM32_PUDR_FLOATING);
	palSetPadMode(GPIOA, 9, PAL_MODE_ALTERNATE(GPIO_AF_TIM1) | PAL_STM32_OSPEED_HIGHEST | PAL_STM32_PUDR_FLOATING);
	palSetPadMode(GPIOA, 10, PAL_MODE_ALTERNATE(GPIO_AF_TIM1) | PAL_STM32_OSPEED_HIGHEST | PAL_STM32_PUDR_FLOATING);

	// L1-L3
	palSetPadMode(GPIOB, 13, PAL_MODE_ALTERNATE(GPIO_AF_TIM1) | PAL_STM32_OSPEED_HIGHEST | PAL_STM32_PUDR_FLOATING);
	palSetPadMode(GPIOB, 14, PAL_MODE_ALTERNATE(GPIO_AF_TIM1) | PAL_STM32_OSPEED_HIGHEST | PAL_STM32_PUDR_FLOATING);
	palSetPadMode(GPIOB, 15, PAL_MODE_ALTERNATE(GPIO_AF_TIM1) | PAL_STM32_OSPEED_HIGHEST | PAL_STM32_PUDR_FLOATING);

	// Hall sensors	
	palSetPadMode(HW_HALL_ENC_GPIO1, HW_HALL_ENC_PIN1, PAL_MODE_INPUT_PULLUP);
	palSetPadMode(HW_HALL_ENC_GPIO2, HW_HALL_ENC_PIN2, PAL_MODE_INPUT_PULLUP);
	palSetPadMode(HW_HALL_ENC_GPIO3, HW_HALL_ENC_PIN3, PAL_MODE_INPUT_PULLUP);

	// Hall filters
	palSetPadMode(HALL_FILTER_GPIO, HALL_FILTER_PIN, PAL_MODE_OUTPUT_PUSHPULL | PAL_STM32_OSPEED_HIGHEST);
	HALL_FILTER_OFF();

	// Phase filters
	palSetPadMode(PHASE_FILTER_GPIO, PHASE_FILTER_PIN1, PAL_MODE_OUTPUT_OPENDRAIN);
	palSetPadMode(PHASE_FILTER_GPIO, PHASE_FILTER_PIN2, PAL_MODE_OUTPUT_OPENDRAIN);
	palSetPadMode(PHASE_FILTER_GPIO, PHASE_FILTER_PIN3, PAL_MODE_OUTPUT_OPENDRAIN);
	PHASE_FILTER_OFF();

	// Current filter is permanent
	/*
	palSetPadMode(CURRENT_FILTER_GPIO1, CURRENT_FILTER_PIN1, PAL_MODE_OUTPUT_PUSHPULL | PAL_STM32_OSPEED_HIGHEST);
	palSetPadMode(CURRENT_FILTER_GPIO2, CURRENT_FILTER_PIN2, PAL_MODE_OUTPUT_PUSHPULL | PAL_STM32_OSPEED_HIGHEST);
	palSetPadMode(CURRENT_FILTER_GPIO3, CURRENT_FILTER_PIN3, PAL_MODE_OUTPUT_PUSHPULL | PAL_STM32_OSPEED_HIGHEST);
	CURRENT_FILTER_OFF();
	*/


	// ADC Pins
	palSetPadMode(GPIOA, 0, PAL_MODE_INPUT_ANALOG);
	palSetPadMode(GPIOA, 1, PAL_MODE_INPUT_ANALOG);
	palSetPadMode(GPIOA, 2, PAL_MODE_INPUT_ANALOG);
	palSetPadMode(GPIOA, 3, PAL_MODE_INPUT_ANALOG);
	palSetPadMode(GPIOA, 5, PAL_MODE_INPUT_ANALOG);
	palSetPadMode(GPIOA, 6, PAL_MODE_INPUT_ANALOG);

	palSetPadMode(GPIOB, 0, PAL_MODE_INPUT_ANALOG);
	palSetPadMode(GPIOB, 1, PAL_MODE_INPUT_ANALOG);

	palSetPadMode(GPIOC, 0, PAL_MODE_INPUT_ANALOG);
	palSetPadMode(GPIOC, 1, PAL_MODE_INPUT_ANALOG);
	palSetPadMode(GPIOC, 2, PAL_MODE_INPUT_ANALOG);
	palSetPadMode(GPIOC, 3, PAL_MODE_INPUT_ANALOG);
	palSetPadMode(GPIOC, 4, PAL_MODE_INPUT_ANALOG);

	//register terminal callbacks	
	terminal_register_command_callback(
		"double_pulse",
		"Start a double pulse test",
		0,
		terminal_cmd_doublepulse);
}
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

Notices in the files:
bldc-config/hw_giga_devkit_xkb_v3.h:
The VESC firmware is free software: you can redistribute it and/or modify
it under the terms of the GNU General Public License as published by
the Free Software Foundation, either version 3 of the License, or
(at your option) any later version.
